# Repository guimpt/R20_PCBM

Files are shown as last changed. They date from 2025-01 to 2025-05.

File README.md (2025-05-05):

# Small High efficiency PCB Motor
## The project
The goal of this project is to create a small and highly efficient and very cheap to manufacture PCB Motor. The "comb" design allows for greater efficiency and torque density.

* **USB-C Powered:** Powered through a standard USB-C connection, making it incredibly user-friendly and compatible with modern power sources.
* **Cost-Effective Manufacturing:** Designed with simplicity and scalability in mind, it is extremely affordable to produce—perfect for hobbyists and large-scale applications alike.
* **Efficient:** The comb-shaped stator maximizes efficiency by eliminating torque loss, ensuring optimal performance even under demanding conditions.
* **Seamless Integration:** Fully customizable, the motor can be easily modified or directly integrated into any project requiring a compact, inexpensive motor solution.
* **Advanced Control Capabilities:** Built-in position, velocity, and torque control offer a level of precision and flexibility typically reserved for far more expensive systems.

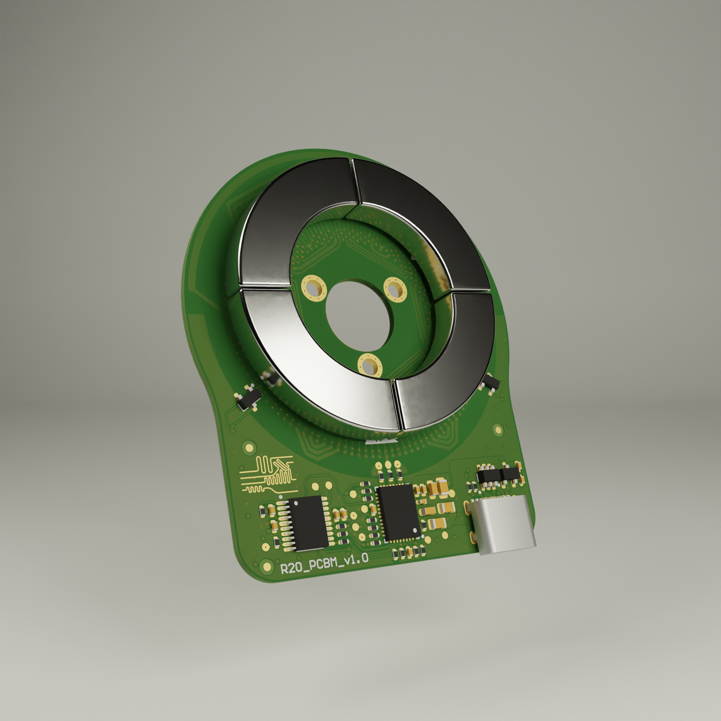
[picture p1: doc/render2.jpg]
Electronics render


## Results
https://github.com/user-attachments/assets/9d861e9e-ca71-4aab-a625-51570a6e43fa

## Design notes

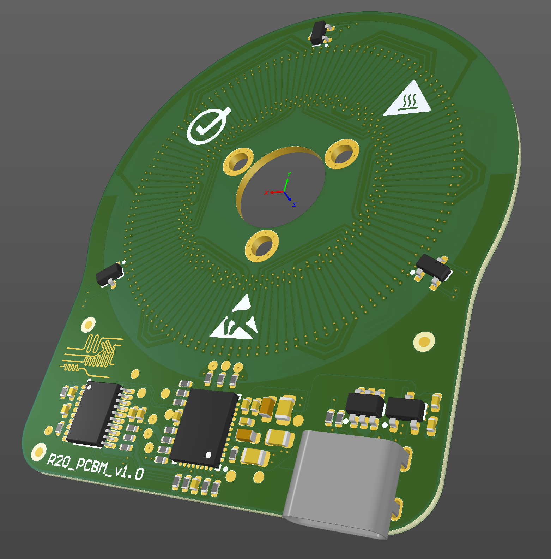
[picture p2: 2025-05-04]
doc/R20_PCBM.png

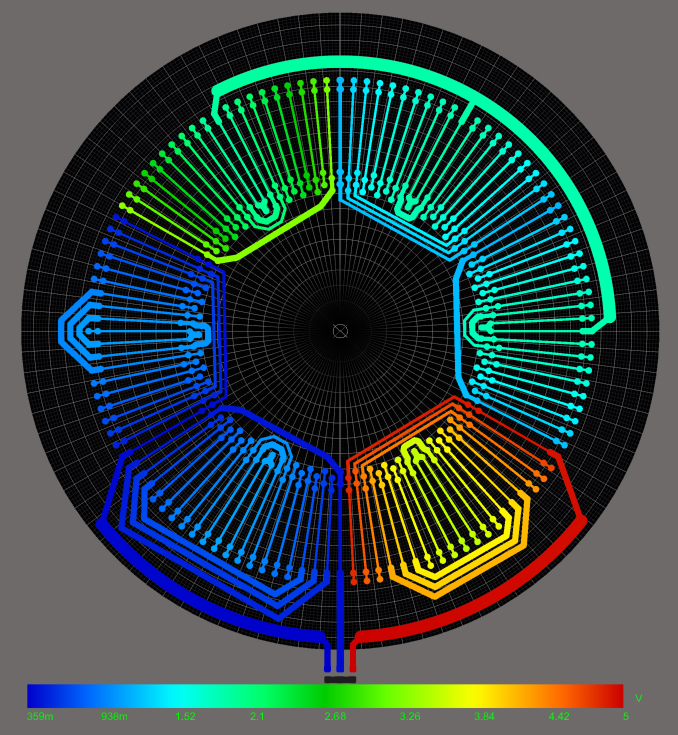
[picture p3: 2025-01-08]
doc/rev3V.png

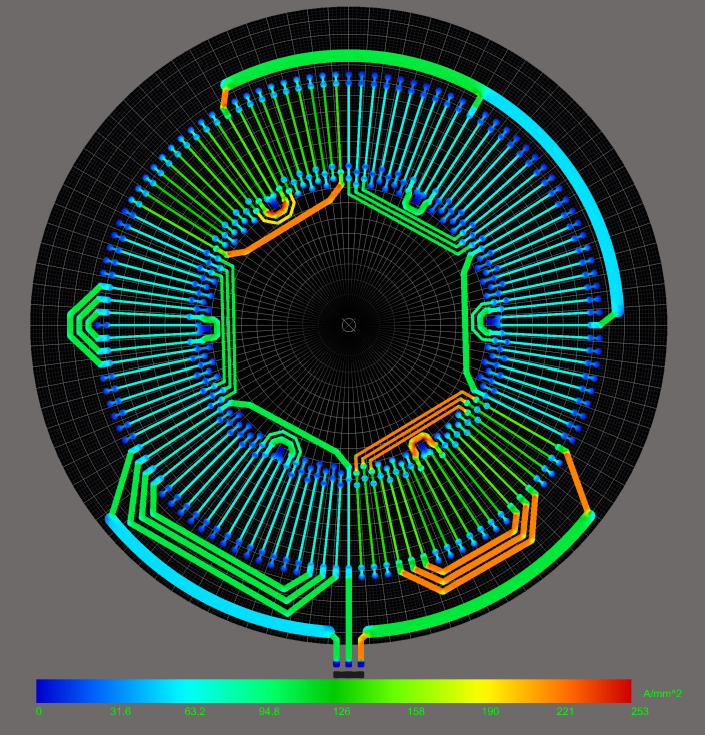
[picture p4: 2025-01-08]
doc/rev3I.png

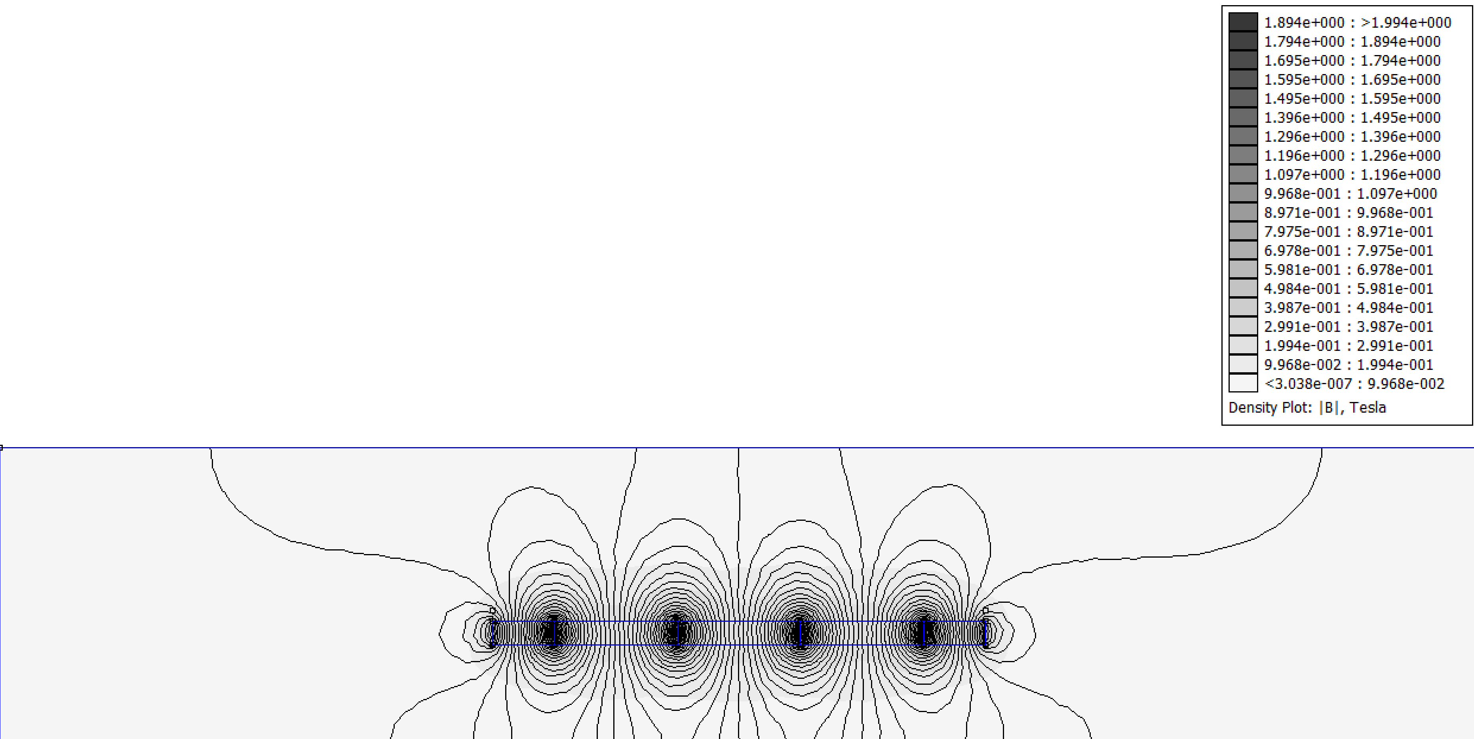
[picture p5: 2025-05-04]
simulation/femm/r20_femm.png

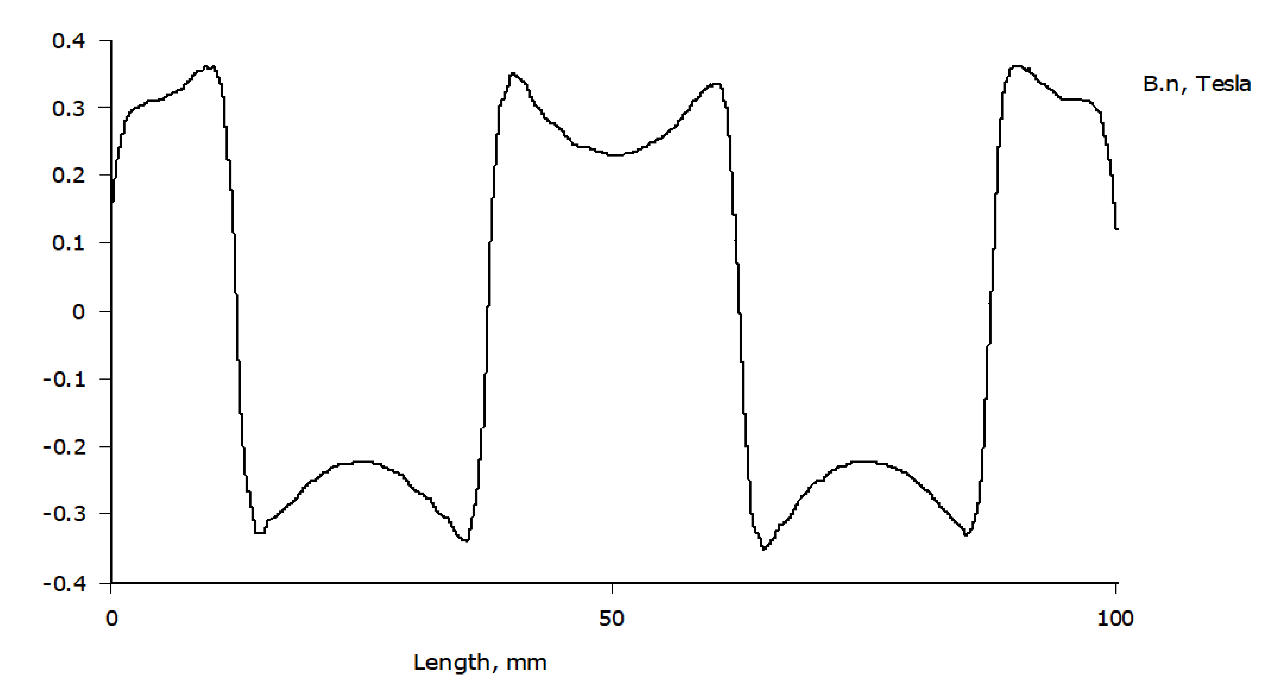
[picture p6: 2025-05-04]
simulation/femm/r20_femm_Bn.png

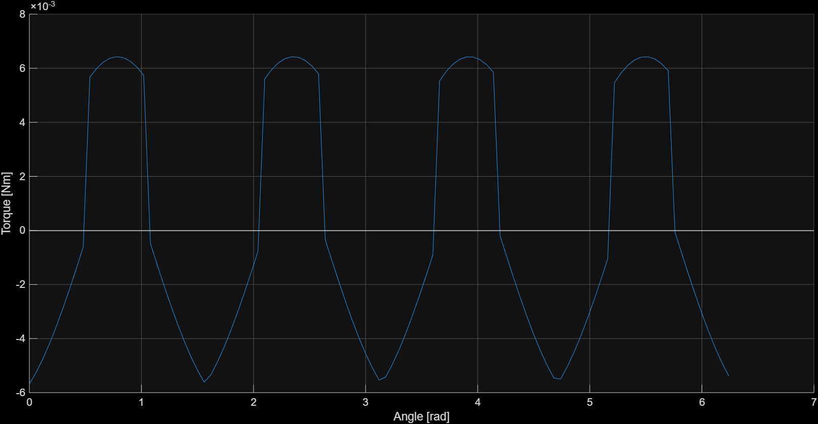
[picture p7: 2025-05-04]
simulation/torque/torque_BC_swapped.png

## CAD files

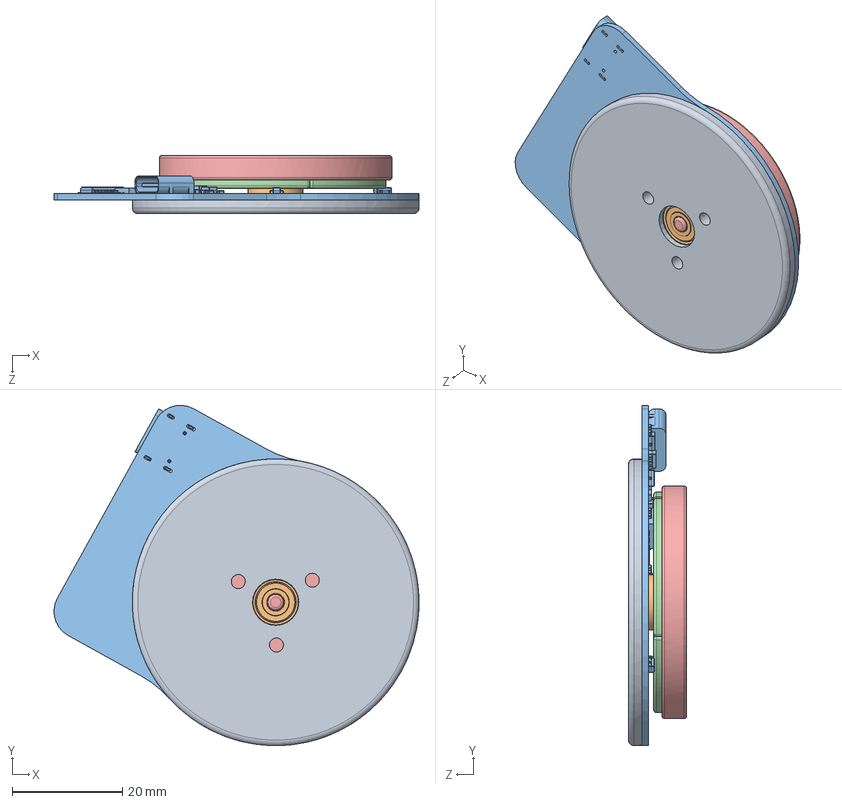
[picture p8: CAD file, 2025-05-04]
Project/CAD/R20_PCBM.SLDASM
66.2 x 61.7 x 10.6 mm
Rotor_pl
magnets x 4
Stator_pcb
623-2z
Stator

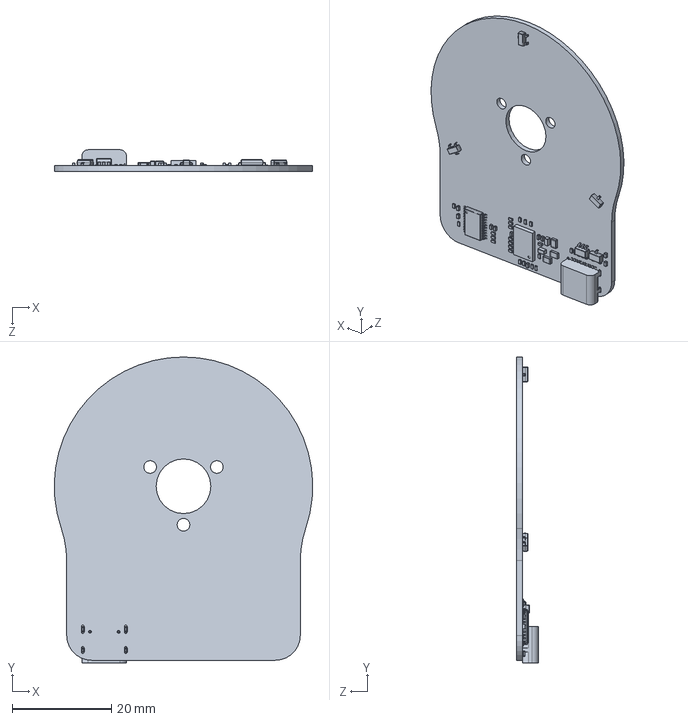
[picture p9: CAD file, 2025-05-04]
Project/CAD/Stator_pcb.SLDPRT
52.0 x 61.6 x 4.33 mm

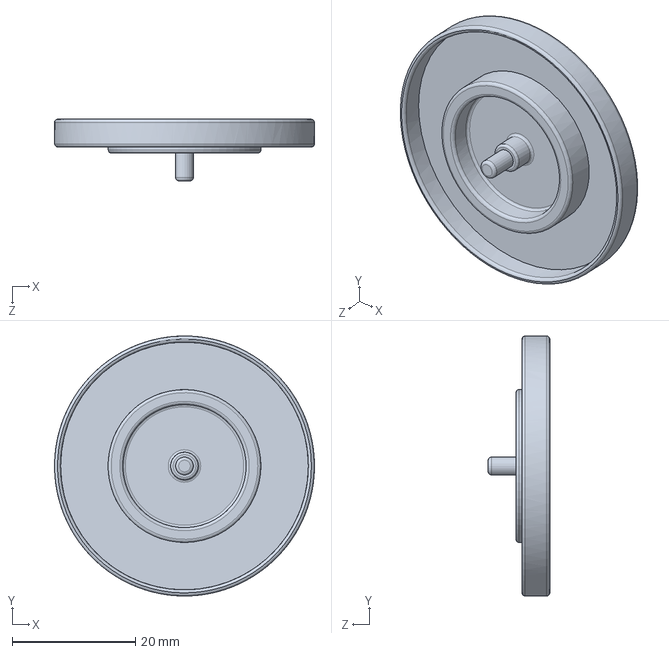
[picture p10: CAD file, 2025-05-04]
Project/CAD/Rotor_pl.SLDPRT
42.2 x 42.2 x 10.0 mm

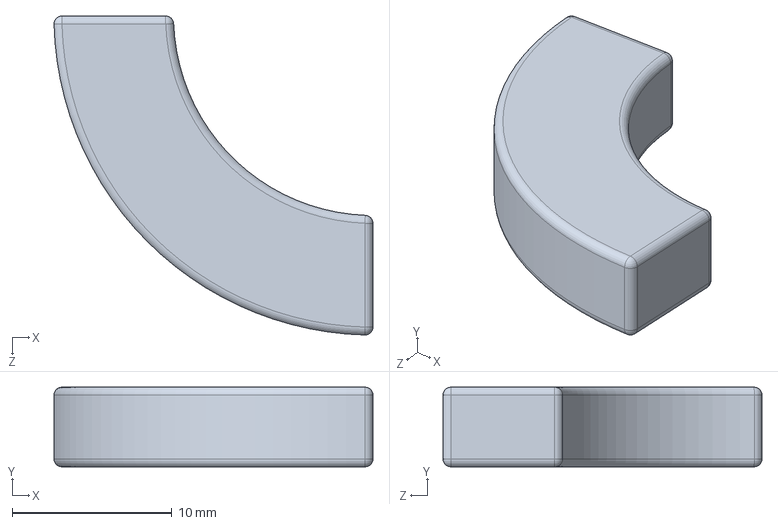
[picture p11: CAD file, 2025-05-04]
Project/CAD/magnets.SLDPRT
20.0 x 5.00 x 20.0 mm

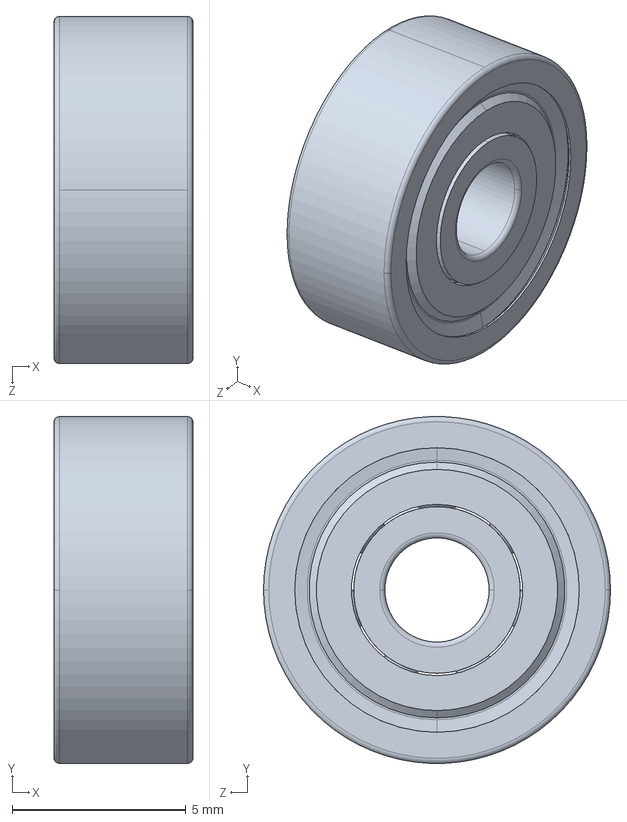
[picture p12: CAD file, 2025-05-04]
Project/CAD/623-2z.SLDPRT
4.00 x 10.0 x 10.0 mm

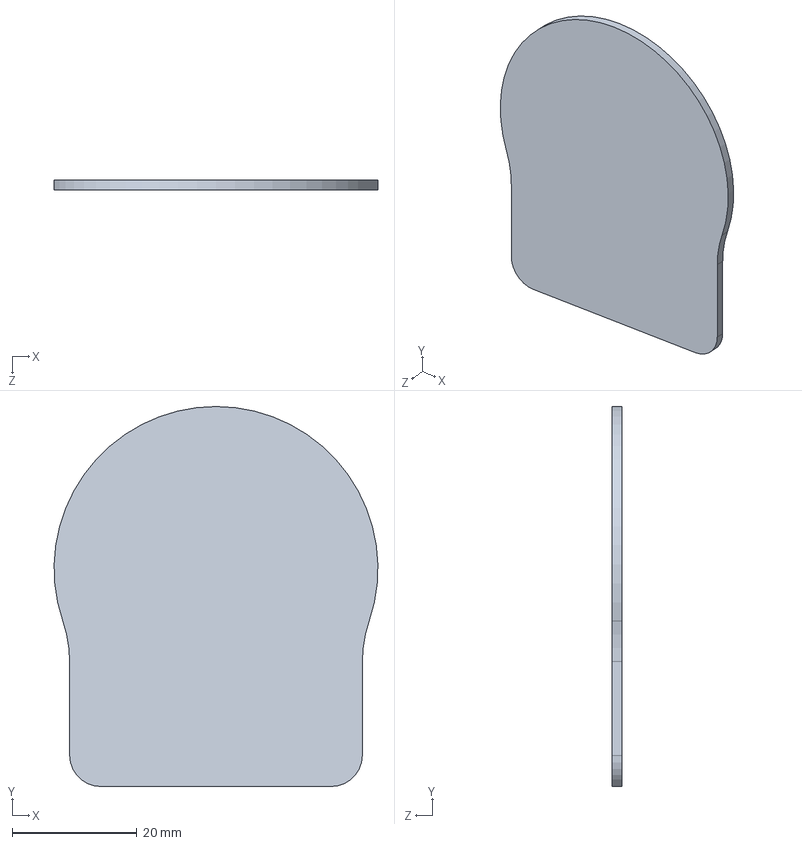
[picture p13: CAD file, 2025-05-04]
Project/CAD/outline.SLDPRT
52.0 x 61.0 x 1.60 mm

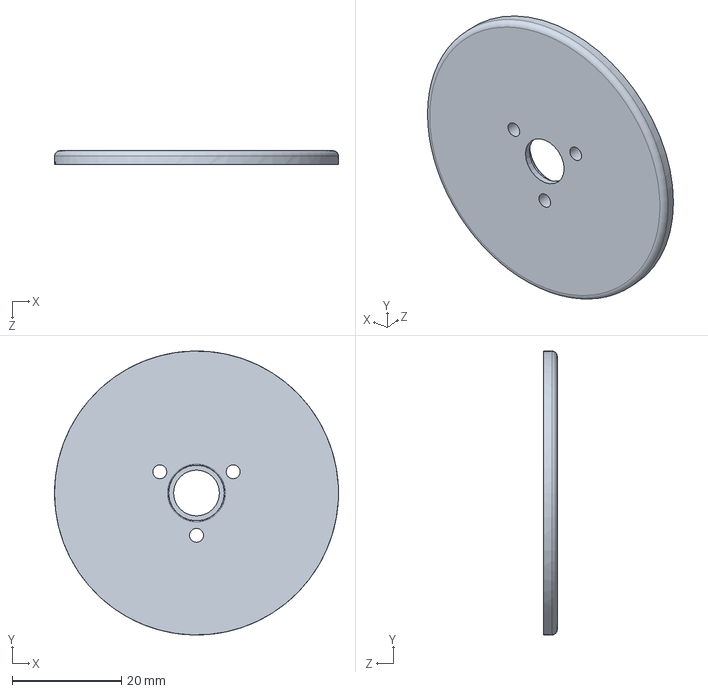
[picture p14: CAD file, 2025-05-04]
Project/CAD/Stator.SLDPRT
52.0 x 52.0 x 2.50 mm

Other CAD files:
Project/CAD/R20_PCBM.x_t

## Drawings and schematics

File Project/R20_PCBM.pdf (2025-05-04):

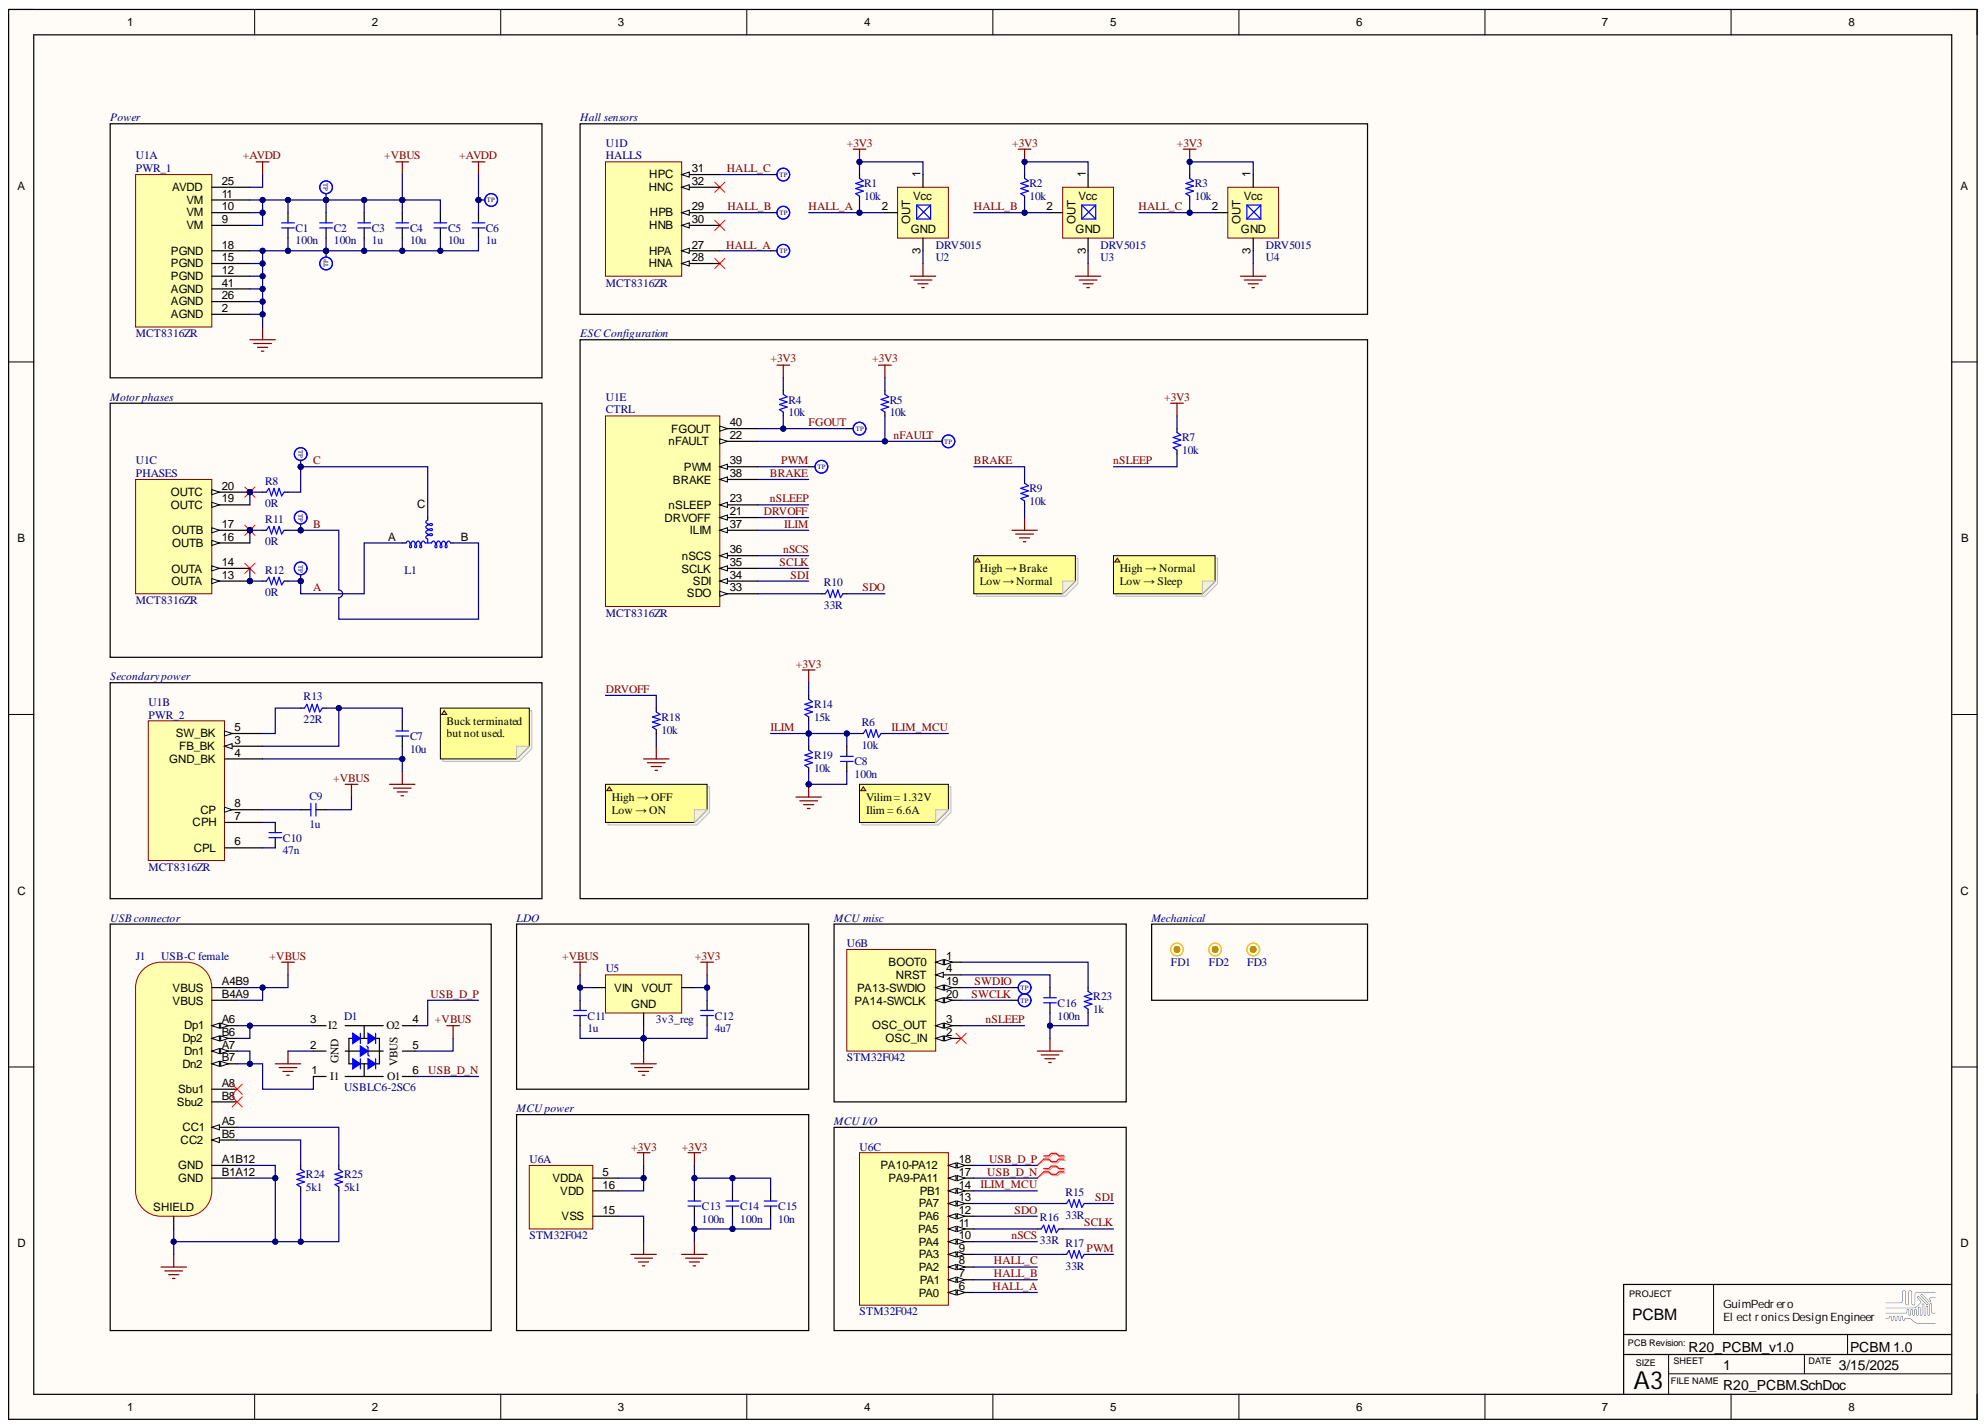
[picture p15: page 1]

PROJECT PCBM | GuimPedr er o El ect r onics Design Engineer

PCB Revision: R20_PCBM_v1.0 | PCBM 1.0

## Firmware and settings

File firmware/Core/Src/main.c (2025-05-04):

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
/* Includes ------------------------------------------------------------------*/
#include "main.h"

/* USER CODE BEGIN Includes */
#include <math.h>
#include <stdlib.h>
#include "mct8316.h"
#include "pid.h"
/* USER CODE END Includes */

/* USER CODE BEGIN PD */
#define VALID_HALL_STATES ((1 << 1) | (1 << 3) | (1 << 2) | (1 << 6) | (1 << 4) | (1 << 5))
#define ALPHA_HALL_SPEED	0.2f
/* USER CODE END PD */

SPI_HandleTypeDef hspi1;

TIM_HandleTypeDef htim2;
TIM_HandleTypeDef htim3;

PCD_HandleTypeDef hpcd_USB_FS;

/* USER CODE BEGIN PV */
MCT8316 mct8316;
volatile int32_t hall_count = 0;
volatile int32_t last_hall_count = 0;
volatile float hall_speed = 0;
volatile uint8_t last_hall_state = 0;
volatile uint32_t last_tick = 0;

PID posPID;
int32_t action_k;
int32_t action_km1;
uint16_t timer_counter = 0;
uint8_t flag_100hz = RESET;
uint8_t flag_10hz = RESET;
uint8_t flag_1hz = RESET;
uint32_t seconds_counter = 0;
/* USER CODE END PV */

void SystemClock_Config(void);
static void MX_GPIO_Init(void);
static void MX_SPI1_Init(void);
static void MX_TIM2_Init(void);
static void MX_USB_PCD_Init(void);
static void MX_TIM3_Init(void);
/* USER CODE BEGIN PFP */
void HAL_GPIO_EXTI_Callback(uint16_t GPIO_Pin);
static inline uint8_t is_valid_hall_state(uint8_t state);
/* USER CODE END PFP */

/**
 * @brief  The application entry point.
 * @retval int
 */
int main(void)
{

	/* MCU Configuration--------------------------------------------------------*/

	/* Reset of all peripherals, Initializes the Flash interface and the Systick. */
	HAL_Init();

	/* Configure the system clock */
	SystemClock_Config();

	/* Initialize all configured peripherals */
	MX_GPIO_Init();
	MX_SPI1_Init();
	MX_TIM2_Init();
	MX_USB_PCD_Init();
	MX_TIM3_Init();
	/* USER CODE BEGIN 2 */

	/* Initialize MCT8316ZR */
	mct8316.hspi=&hspi1;
	MCT8316_Init(&mct8316);

	/* Initialize PWM generation */
	HAL_TIM_PWM_Start(&htim2, TIM_CHANNEL_4);

	/* Initialize PID timer */
	HAL_TIM_Base_Start_IT(&htim3);
	//	TIM2->CCR4 = 50;
	TIM2->CCR4 = 0;
	MCT8316_SetDirection(&mct8316,1);

	posPID.Umax = 50;
	posPID.Umin = -50;
	posPID.kd = 0.001;
	posPID.kp = 1;
	posPID.ki = 0;
	posPID.loop_freq = 1000; //[Hz]
	posPID.w_cutoff = 5;
	PID_Initialize(&posPID);

	posPID.x_k = 50 * posPID.multiplier;

	uint8_t enable_flag = SET;

	HAL_Delay(10000);


	/* USER CODE END 2 */

	/* Infinite loop */
	/* USER CODE BEGIN WHILE */
	while (1)
	{
		if(posPID.update_flag && enable_flag){
			posPID.update_flag = RESET;
			posPID.h_k = hall_count * posPID.multiplier;
			PID_Update(&posPID);
			action_k = posPID.y_k / ((int32_t)posPID.multiplier);
			TIM2->CCR4 = abs(action_k)+18;
		}
		if(flag_100hz && enable_flag){
			flag_100hz = RESET;
			if(__SIGN(action_k) != __SIGN(action_km1)){
				if(__SIGN(action_k) == 1) MCT8316_SetDirection(&mct8316,1);
				else if(__SIGN(action_k) == -1) MCT8316_SetDirection(&mct8316,0);
			}
			action_km1 = action_k;
		}
		if(flag_10hz){
			flag_10hz = RESET;
			hall_speed = ALPHA_HALL_SPEED*(((float)(hall_count - last_hall_count)) * 10.f / 12.f) +
					(1.f - ALPHA_HALL_SPEED) * hall_speed;
			last_hall_count = hall_count;
			MCT8316_UpdateStatus(&mct8316); // TODO check errors and clear if needed
		}
		if(flag_1hz){
			flag_1hz = RESET;
			seconds_counter++;
			if(seconds_counter == 3) {
				posPID.x_k = -50 * posPID.multiplier;
			}
			else if(seconds_counter == 6) {
				posPID.x_k = 98 * posPID.multiplier;
			}
			else if(seconds_counter == 10) {
				posPID.x_k = -98 * posPID.multiplier;
			}
			else if(seconds_counter == 15)
				posPID.x_k = 206 * posPID.multiplier;
			}
			else if(seconds_counter == 20) {
				posPID.x_k = -206 * posPID.multiplier;
			}
			else if(seconds_counter == 25) {
				posPID.x_k = 302 * posPID.multiplier;
			}
			else if(seconds_counter == 30) {
				posPID.x_k = -302 * posPID.multiplier;
			}

		/* USER CODE END WHILE */

		/* USER CODE BEGIN 3 */
	}
	/* USER CODE END 3 */
}

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
/* USER CODE BEGIN 4 */

// Function to check if a Hall state is valid using bitmasking
static inline uint8_t is_valid_hall_state(uint8_t state)
{
	return (VALID_HALL_STATES & (1 << state)) != 0;
}

void HAL_GPIO_EXTI_Callback(uint16_t GPIO_Pin)
{
	uint32_t gpio_read = HALL_A_GPIO_Port->IDR;
	uint8_t hall_state;

	// Read the current Hall state
	hall_state = (__HALL_READ(gpio_read, HALL_A_Pin) << 2) |
			(__HALL_READ(gpio_read, HALL_B_Pin) << 1) |
			(__HALL_READ(gpio_read, HALL_C_Pin) << 0);

	// Ignore noise: process only if it's a valid Hall state
	if (!is_valid_hall_state(hall_state))
	{
		return;  // Skip invalid states (caused by noise)
	}

	// Determine direction based on the Hall sequence
	if (((last_hall_state == 0b001) && (hall_state == 0b011)) ||
			((last_hall_state == 0b011) && (hall_state == 0b010)) ||
			((last_hall_state == 0b010) && (hall_state == 0b110)) ||
			((last_hall_state == 0b110) && (hall_state == 0b100)) ||
			((last_hall_state == 0b100) && (hall_state == 0b101)) ||
			((last_hall_state == 0b101) && (hall_state == 0b001)))
	{
		hall_count++;
	}
	else if (((last_hall_state == 0b001) && (hall_state == 0b101)) ||
			((last_hall_state == 0b101) && (hall_state == 0b100)) ||
			((last_hall_state == 0b100) && (hall_state == 0b110)) ||
			((last_hall_state == 0b110) && (hall_state == 0b010)) ||
			((last_hall_state == 0b010) && (hall_state == 0b011)) ||
			((last_hall_state == 0b011) && (hall_state == 0b001)))
	{
		hall_count--;
	}

	// Update last state
	last_hall_state = hall_state;

}


/**
  * @brief This function handles TIM3 global interrupt.
  */
void TIM3_IRQHandler(void)
{
  HAL_TIM_IRQHandler(&htim3);
  posPID.update_flag = SET;
  if(++timer_counter >= 1000) {
	  timer_counter = 0;
	  flag_1hz = SET;
  }
  if((timer_counter%10) == 0) { // 100Hz
	  flag_100hz = SET;
	  if((timer_counter%100) == 0) flag_10hz = SET; // 10Hz
  }
}

/* USER CODE END 4 */
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


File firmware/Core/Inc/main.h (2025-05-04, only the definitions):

#define HALL_A_Pin GPIO_PIN_0
#define HALL_A_GPIO_Port GPIOA
#define HALL_A_EXTI_IRQn EXTI0_1_IRQn
#define HALL_B_Pin GPIO_PIN_1
#define HALL_B_GPIO_Port GPIOA
#define HALL_B_EXTI_IRQn EXTI0_1_IRQn
#define HALL_C_Pin GPIO_PIN_2
#define HALL_C_GPIO_Port GPIOA
#define HALL_C_EXTI_IRQn EXTI2_3_IRQn
#define PWM_Pin GPIO_PIN_3
#define PWM_GPIO_Port GPIOA
#define SPI1_CS_Pin GPIO_PIN_4
#define SPI1_CS_GPIO_Port GPIOA

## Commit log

2025-01-08 Improved motor footprint with simulation information
    [R20_PCBM.PcbDoc, R20_PCBM.PcbLib]
2025-01-08 Small footprint tweaks to improve motor thermal performance
    [R20_PCBM.PcbDoc, R20_PCBM.PcbLib]
2025-01-08 Added internal hole
2025-01-08 Added THT holes
    [R20_PCBM.PrjPcb, R20_PCBM.SchDoc, R20_PCBM.SchLib]
2025-01-17 Added ESC and rough component layout
    [R20_PCBM.PcbLib, R20_PCBM.SchDoc, R20_PCBM.SchLib]
2025-01-17 Added matlab torque simulations
2025-01-20 Added TVS diode
    [R20_PCBM.PcbDoc, R20_PCBM.PcbLib, R20_PCBM.SchDoc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]
2025-01-20 Continued layout
    [R20_PCBM.PcbDoc, R20_PCBM.SchDoc]
2025-01-23 Continued layout and added silkscreen
    [R20_PCBM.PcbLib]
2025-01-31 Added bomdoc and outjob
    [R20_PCBM.PrjPcb, R20_PCBM.SchDoc]
2025-03-18 Started working on firmware
    [623-2z.SLDPRT, R20_PCBM.SLDASM, R20_PCBM.x_t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]
2025-03-19 Configured PWM generation
2025-03-19 Implemented HALL counter logic
2025-04-10 Fixed SPI communications & hall position decoding
    [main.c, main.h, mct8316.c]
2025-04-12 Velocity loop closed
2025-04-26 Added simulations and swapped B and C hall sensors.
    [R20_PCBM.PrjPcb]
2025-05-02 Release candidate
    [R20_PCBM.PrjPcb]

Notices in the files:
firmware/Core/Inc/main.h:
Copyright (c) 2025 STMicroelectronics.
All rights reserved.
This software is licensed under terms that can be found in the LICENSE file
